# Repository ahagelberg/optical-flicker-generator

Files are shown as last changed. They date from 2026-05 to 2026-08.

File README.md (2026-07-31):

# Optical Flicker Generator

Optical Flicker Generator is a complete hardware + firmware device for controlled high-power optical stimulation.

Current hardware platform:

- Arduino MKR Zero
- Arduino Ethernet Shield
- Custom PCB with high-current LED driver stages

Current software provides:

- Web control page (`/`)
- Web configuration page (`/config`)
- HTTP JSON API
- ASCII shell over Serial and optional Telnet

## Project Scope

- Firmware source code is under `firmware/`.
- Hardware design files (schematics/PCB/manufacturing outputs) are under `hardware/`.

## Documentation

- User manual: `firmware/USER_MANUAL.md`
- Interface/protocol reference: `firmware/PROTOCOL.md`

## Getting Started

1. Flash the firmware to the device.
2. Connect power and Ethernet.
3. Open the control page in a browser using:
   - `http://flicker-<suffix>.local/`, or
   - the IP shown on the device display.

## Repository Layout

- `firmware/` - PlatformIO firmware source and documentation
- `hardware/` - Hardware design files

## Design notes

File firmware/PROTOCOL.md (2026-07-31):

# Optical Flicker Generator — Interface & Protocol Reference

**Document firmware version: 1.1**

Commands and fields are tagged with **Since** (first firmware version that includes them). Untagged items apply since **1.0**. Use `identify` or `status` to read the device firmware version at runtime.

## Overview

The device exposes three interfaces:

| Interface | Transport | Port | Format |
| --- | --- | --- | --- |
| ASCII shell | USB Serial (CDC)  | — | Line-oriented text |
| ASCII shell | Ethernet / Telnet | TCP 23 | Same as Serial |
| HTTP API | Ethernet | TCP 80 | JSON |

All LED control goes through `FlickerController`, so frequency calibration applies uniformly regardless of which interface is used. The output is two hardware channels (MKR Zero D2 and D3) driven in lockstep with the same PWM parameters; there is no per-channel control.

---

## ASCII Shell (Serial + Telnet)

### Framing

- One command per line, terminated by `\n` or `\r\n`.
- Command verb is **case-insensitive**; arguments are case-sensitive where noted.
- Response is a single line terminated by `\r\n` (Arduino `println`).
- Max command line length: 128 bytes (excess bytes are discarded; the line is dropped).
- Partial lines with no new data for 5 s are silently discarded.

### Response format

```
OK                     # success, no payload
OK <payload>           # success with data
ERROR <reason>         # failure; reason is human-readable
```

Errors always begin with the literal string `ERROR`  followed by a short description. Scripts should match on the prefix.

Status/debug lines emitted asynchronously on USB Serial always begin with `# ` and must be ignored by API clients. (**Since 1.1**)

### Command summary

| Command | Since | Description |
| --- | ----- | --- |
| `identify` | 1.0 | Device type, firmware version, hardware ID |
| `status` | 1.1 | One-line `key=value` system status dump |
| `reboot` | 1.1 | Soft-reset the MCU |
| `mode` | 1.0 | Query/set operating mode |
| `frequency` / `freq` | 1.0 | Query/set envelope frequency (Hz) |
| `dutycycle` / `duty` | 1.0 | Query/set duty cycle (%) |
| `intensity` / `int` | 1.0 | Query/set intensity (%) |
| `carrier` | 1.0 | Query/set PWM carrier (Hz), persisted |
| `screensaver` | 1.0 | Query/set display screensaver timeout (s), persisted |
| `calibration` | 1.0 | Print stored frequency calibration table |
| `calibrate` | 1.0 | Start interactive calibration wizard |

---

### Commands

#### `identify`

**Since:** 1.0

Query device identity.

```
→ identify
← OK FLICKER_DEVICE 1.1 A0B1C2D3E4F56789A0B1C2D3E4F56789
```

Payload: `<device_type> <firmware_version> <id>`  
`<id>` is the SAMD21 128-bit hardware serial number encoded as 32 uppercase hex chars.

---

#### `status`

**Since:** 1.1

Dump system status as one line of space-separated `key=value` fields. Values contain no spaces. Parse by splitting on spaces, then on the first `=` in each token.

```
→ status
← OK STATUS device=FLICKER_DEVICE firmware=1.1 id=A0B1C2D3E4F56789A0B1C2D3E4F56789 mode=flicker frequency=50 dutycycle=50 intensity=100 carrier=20000 screensaver=10 dhcp=1 ip=192.168.1.10 ethernet=up hardware=W5500 link=on mdns=flicker-a1b2c3 cal_points=8 wizard=0 uptime_ms=12345
```

| Key | Meaning |
| --- | --- |
| `device` | Device type string |
| `firmware` | Firmware version |
| `id` | 32-char uppercase hex SAMD21 unique ID |
| `mode` | `off` / `constant` / `flicker` / `sinus` |
| `frequency` | Desired envelope Hz |
| `dutycycle` | Duty cycle % |
| `intensity` | Intensity % |
| `carrier` | PWM carrier Hz |
| `screensaver` | Display screensaver timeout (s) |
| `dhcp` | `1` if DHCP enabled, else `0` |
| `ip` | Current IPv4 address (`0.0.0.0` if none) |
| `ethernet` | `up` if hardware + link + IP, else `down` |
| `hardware` | `none` / `W5100` / `W5200` / `W5500` |
| `link` | PHY link `on` / `off` / `unknown` |
| `mdns` | mDNS hostname without `.local` |
| `cal_points` | Stored calibration point count |
| `wizard` | `1` if calibration wizard active |
| `uptime_ms` | Milliseconds since boot |

`status` and `reboot` are accepted even while the calibration wizard is active.

---

#### `reboot`

**Since:** 1.1

Reboot the MCU after queuing the reply.

```
→ reboot
← OK
```

The reply is written to the serial/TCP output path before reset. The USB or TCP connection will drop.

---

#### `mode [value]`

**Since:** 1.0

Query or set the operating mode.

```
→ mode
← OK flicker

→ mode flicker
← OK
```

Valid modes: `off`, `constant`, `flicker`, `sinus`  
Changing mode keeps existing frequency/duty/intensity values; only the mode changes.

| Mode | Description |
| --- | --- |
| `off` | LED output disabled |
| `constant` | Continuous illumination at the configured intensity |
| `flicker`  | Square-wave envelope at configured frequency and duty cycle |
| `sinus` | Sinusoidal envelope at configured frequency |

---

#### `frequency` / `freq [value]`

**Since:** 1.0

Query or set the flicker/sinus frequency in Hz.

```
→ frequency
← OK 50

→ freq 10
← OK

→ freq 0
← ERROR out of range (1-500 Hz)
```

Range: 1–500 Hz  
The value is the **desired** physical Hz; `FlickerController` applies the calibration table before commanding the hardware. Setting frequency does not change mode.

---

#### `dutycycle` / `duty [value]`

**Since:** 1.0

Query or set the duty cycle percentage (flicker mode only; stored for other modes too).

```
→ duty
← OK 50

→ duty 30
← OK

→ duty 5
← ERROR out of range (10-90 %)
```

Range: 10–90 %

---

#### `intensity` / `int [value]`

**Since:** 1.0

Query or set the LED intensity percentage.

```
→ intensity
← OK 100

→ int 75
← OK
```

Range: 0–100 %

---

#### `carrier [value]`

**Since:** 1.0

Query or set the PWM carrier frequency in Hz. The carrier drives intensity modulation in `constant` and `sinus` modes; it has no effect in `flicker` mode. The value is persisted to EEPROM immediately.

```
→ carrier
← OK 20000

→ carrier 10000
← OK

→ carrier 500
← ERROR out of range (1000-50000 Hz)
```

Range: 1 000–50 000 Hz

---

#### `screensaver [value]`

**Since:** 1.0

Query or set the OLED screensaver timeout in seconds. The value is persisted to EEPROM immediately. After this many seconds with no set-button activity, the display enters power-save; a short press wakes it.

```
→ screensaver
← OK 10

→ screensaver 30
← OK

→ screensaver 0
← ERROR out of range (1-600 s)
```

Range: 1–600 s

---

#### `calibration`

**Since:** 1.0

Print the stored frequency calibration table.

```
→ calibration
← OK CAL 0
```

*(no calibration stored)*

```
→ calibration
← OK CAL 8 1:1;5:5;10:10;25:26;50:51;100:103;200:206;500:515
```

*(8 points stored)*

Payload format: `OK CAL <count> [cmd1:meas1;cmd2:meas2;…]`  

- `count` — number of stored calibration points.  
- Each pair is `<commanded_hz>:<measured_hz>` separated by `;`.

---

#### `calibrate`

**Since:** 1.0

Start the interactive frequency calibration wizard.

The wizard drives the LED at each of 8 nominal frequencies (1, 5, 10, 25, 50, 100, 200, 500 Hz) in sequence. At each step, the device replies with a prompt; the user measures the actual output frequency and sends it as a plain integer.

**Wizard session:**

```
→ calibrate
← OK WIZARD 1/8 1        # step/total, target Hz

→ 1                       # measured Hz (integer)
← OK WIZARD 2/8 5

→ 5
← OK WIZARD 3/8 10

→ 11
← OK WIZARD 4/8 25
…
→ 519
← OK WIZARD DONE          # table saved, prior mode restored
```

**Wizard prompt format:** `OK WIZARD <step>/<total> <target_hz>`

While the wizard is active, the shell is in measurement mode — lines that are not a valid unsigned integer receive `ERROR expected measured Hz as integer` and the step is re-prompted. Other commands are rejected except **`status`** and **`reboot`** (**Since 1.1**), which remain available during the wizard.

The wizard forces `flicker` mode during measurement (for a stable square-wave envelope) while preserving the user's configured duty cycle and intensity. Calibration bypass is enabled so raw Hz values drive the hardware. On completion, the prior mode and frequency are restored and calibration is applied immediately.

**Errors:**

```
→ calibrate
← ERROR wizard already active   # sent while wizard is in progress
```

---

### Error reference

| Message | Cause | Since |
| --- | --- | ----- |
| `ERROR empty command` | Line contained no token | 1.0 |
| `ERROR unknown command` | Verb not recognised | 1.0 |
| `ERROR invalid argument` | Argument not parseable | 1.0 |
| `ERROR unknown mode (off constant flicker sinus)` | Unrecognised mode name | 1.0 |
| `ERROR out of range (1-500 Hz)` | Frequency outside 1–500 Hz | 1.0 |
| `ERROR out of range (10-90 %)` | Duty cycle outside 10–90 % | 1.0 |
| `ERROR out of range (0-100 %)` | Intensity outside 0–100 % | 1.0 |
| `ERROR out of range (1000-50000 Hz)` | Carrier frequency outside 1 000–50 000 Hz | 1.0 |
| `ERROR out of range (1-600 s)` | Screensaver timeout outside 1–600 s | 1.0 |
| `ERROR wizard already active` | `calibrate` sent while wizard running | 1.0 |
| `ERROR expected measured Hz as integer` | Non-integer sent during wizard | 1.0 |

---

## HTTP / JSON API

Base URL: `http://<device-ip>/`

Responses use `Content-Type: application/json` and `Connection: close`.

### `GET /api/identify`

```json
{
  "device": "FLICKER_DEVICE",
  "firmware": "1.1",
  "id": "A0B1C2D3E4F56789A0B1C2D3E4F56789"
}
```

---

### `GET /api/state`

Returns the current mode and all parameters.

```json
{
  "mode": "flicker",
  "frequency": 50,
  "dutycycle": 50,
  "intensity": 100
}
```

`frequency` reflects the user's **desired** Hz value, not the calibrated command value sent to hardware.

---

### `POST /api/off`

Turns the LED off. No request body required.

```json
{ "ok": true }
```

---

### `POST /api/constant`

Sets constant mode. Optional JSON body applies parameters before switching.

```json
{ "intensity": 75 }
→
{ "ok": true }
```

---

### `POST /api/flicker`

Sets flicker mode. Optional JSON body applies parameters before switching.

```json
{ "frequency": 10, "dutycycle": 30, "intensity": 80 }
→
{ "ok": true }
```

JSON keys: `frequency` (Hz, 1–500), `dutycycle` (%, 10–90), `intensity` (%, 0–100). All are optional; omit any key to keep the current value.

---

### `POST /api/sinus`

Sets sinus mode. Optional JSON body.

```json
{ "frequency": 25, "intensity": 100 }
→
{ "ok": true }
```

---

### `GET /api/frequency`

```json
{ "frequency": 50 }
```

### `POST /api/frequency`

```json
{ "value": 25 }
→
{ "ok": true }
```

### `GET /api/dutycycle` / `POST /api/dutycycle`

Same pattern. POST body: `{ "value": 40 }`.

### `GET /api/intensity` / `POST /api/intensity`

Same pattern. POST body: `{ "value": 80 }`.

---

### HTTP error responses

```json
{ "error": "Not found" }      // 404 — unknown path
{ "error": "Bad request" }    // 400 — unknown API endpoint
```

Note: the mode-set POST endpoints (`/api/flicker`, `/api/sinus`, etc.) do **not** validate individual parameter ranges — out-of-range values are silently clamped by `FlickerController`. Use the ASCII shell if you need explicit range errors.

---

### Web UI

`GET /` — HTML control page for interactive use.  
`GET /config` — HTML network configuration page (DHCP, static IP/gateway/subnet, PWM carrier frequency).  
`POST /config` — Submit configuration form. Changes take effect on next boot for network settings.

---

## Frequency Calibration

### Concept

Hardware timer resolution means the actual output frequency deviates slightly from the commanded value, especially at the low and high ends of the range. The calibration table stores (commanded Hz, measured Hz) pairs from a one-time wizard run. When a desired frequency `D` is requested, `FlickerController` computes the command value `C` such that the hardware actually outputs `D` Hz, using piecewise-linear inverse interpolation over the stored pairs.

### Math

Points are stored sorted by commanded Hz (the wizard steps are monotonically increasing). For a desired frequency `D`:

1. If the table has fewer than 2 points → identity (`C = D`).
2. If `D ≤ meas[0]` → clamp to `cmd[0]`.
3. If `D ≥ meas[n-1]` → clamp to `cmd[n-1]`.
4. Otherwise find `i` where `meas[i] ≤ D ≤ meas[i+1]` and interpolate:

```
C = cmd[i] + (D - meas[i]) × (cmd[i+1] - cmd[i]) / (meas[i+1] - meas[i])
```

Integer arithmetic; uses 64-bit intermediate to avoid overflow.

### Persistence

The calibration table is stored in EEPROM (SAMD21 flash emulation via `FlashStorage_SAMD`) as part of `StoredConfig` (magic `0x464C4353`). It is treated as factory data and is **not** cleared by a factory reset. Re-running `calibrate` replaces the entire table.

---

## Network configuration

Configured via the `/config` web page or directly in EEPROM. Stored fields:

| Field | Default |
| --- | --- |
| DHCP | enabled |
| Static IP | 0.0.0.0 |
| Gateway | 0.0.0.0 |
| Subnet | 0.0.0.0 |
| PWM carrier Hz | 20000 |

The PWM carrier frequency (1 000–50 000 Hz) controls the intensity modulation rate in `constant` and `sinus` modes. It has no effect in `flicker` mode.

Network changes take effect after a power cycle.

---

## mDNS discovery

The device advertises itself on the LAN via **mDNS/DNS-SD** (UDP port 5353).

| Item | Value |
| ---- | ----- |
| Hostname | `flicker-` + last 6 hex digits of device serial (e.g. `flicker-a1b2c3.local`) |
| Service | `_http._tcp` on port 80 |

After the device has an IP address, open `http://flicker-<suffix>.local/` in a browser, or ping the hostname:

```
ping flicker-a1b2c3.local
```

**Linux:** `avahi-browse -a | grep -i flicker`

**macOS:** mDNS is built in; Safari Bonjour bookmarks also list `_http._tcp` services.

**Windows:** Built-in mDNS support varies by version. Install [Bonjour Print Services](https://support.apple.com/kb/DL999) if `.local` names do not resolve.

mDNS is always enabled when Ethernet has a valid IP. No configuration required.

---

## Set button

Short press on set button wakes the display from screensaver.

Hold set button for **10 s** to perform a factory reset: network settings and PWM carrier Hz are cleared to defaults. The frequency calibration table is **preserved**.

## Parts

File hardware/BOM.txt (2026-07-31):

Model				Manufacturer	Description								Count	á-price (SEK)	price (SEK)
ABX00012			Arduino			Arduino MKR ZERO Microcontroller		1		313.00			313.00
ASX00006			Arduino			Arduino MKR ETH-shield					1		328.00			328.00
TSR 1-2450			Traco			TracoPower voltage reg 5V 1A			1		67.00			67.00
IRLML6344TRPBF		Infineon		MOSFET N-ch 5A 30V SOT-23				4		5.92			23.68
B340AE-13			DiodesZetex		Schottky-diode 40V 3A SMA				4		1.81			7.24
									Resistor 220R 0805						4		0.10			0.40
									Resistor 10K 0805						4		0.10			0.40
EEEFK1H221GP		Panasonic		Electrolytic 220uF 50V SMD				1		12.00			12.00
MDOB128064V2V-WI	Midas			OLED display 0.96" 128x64px				1		156.00			156.00	
1213C BLACK			APEM			Tryckknapp panel 12.2mm					1		67.00			67.00
XHP-2				JST				XHP connector, female, 2-way, 2.5mm		6		0.74			4.44
XHP-4				JST				XHP connector, female, 4-way, 2.5mm		1		1.20			1.20
B2B-XH-A(LF)(SN)	JST				XHP PCB connector, male, 2-way, 2.5mm	4		1.76			7.04
B4B-XH-A(LF)(SN)	JSP				XHP PCB connector, male, 4-way, 2.5mm	1		1.44			1.44
SXH-001T-P0.6N		JST				XH contact element, crimp, AWG22-26		14		0.828			11.592
GST120A24-P1M		Meanwell		AC/DC-adapter 120W 24VDC 5A				1		450.25			450.25
RSTA4265			Radium			LED-list 5000mm 4000K 24V 1000lm/m		1		505.80			505.80
124-618				RS PRO			M12 connector straight male 4-way		2		57.68			115.36
M12A-04PFFS-SH8001	Amphenol		M12 connector panel female 4-way		2		65.30			130.60

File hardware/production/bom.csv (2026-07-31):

Designator | Footprint | Quantity | Value | LCSC Part #
C1 | CP_Elec_10x10.5 | 1 | 470μF
D1, D2, D3, D4 | D_SMA | 4 | D_Schottky
J1, J2, J3, J4 | JST_XH_B2B-XH-A_1x02_P2.50mm_Vertical | 4 | Channel 1
J5 | JST_XH_B2B-XH-A_1x02_P2.50mm_Vertical | 1 | Reset Button
J6 | JST_XH_B2B-XH-A_1x02_P2.50mm_Vertical | 1 | Set Button
J7 | JST_XH_B4B-XH-A_1x04_P2.50mm_Vertical | 1 | OLED 128X64 0.96
J8 | JST_XH_B2B-XH-A_1x02_P2.50mm_Vertical | 1 | 24V
Q1, Q2, Q3, Q4 | SOT-23 | 4 | AO3400A / IRLML6344TRPBF
R1, R3, R5, R7 | 0805 | 4 | 220Ω
R2, R4, R6, R8 | 0805 | 4 | 10K
U1 | Arduino_MKR | 1 | Arduino_MKR
U2 | Converter_DCDC_TRACO_TSR0.5-24xx_TSR0.5-24xxx_THT | 1 | TSR0.5-2450

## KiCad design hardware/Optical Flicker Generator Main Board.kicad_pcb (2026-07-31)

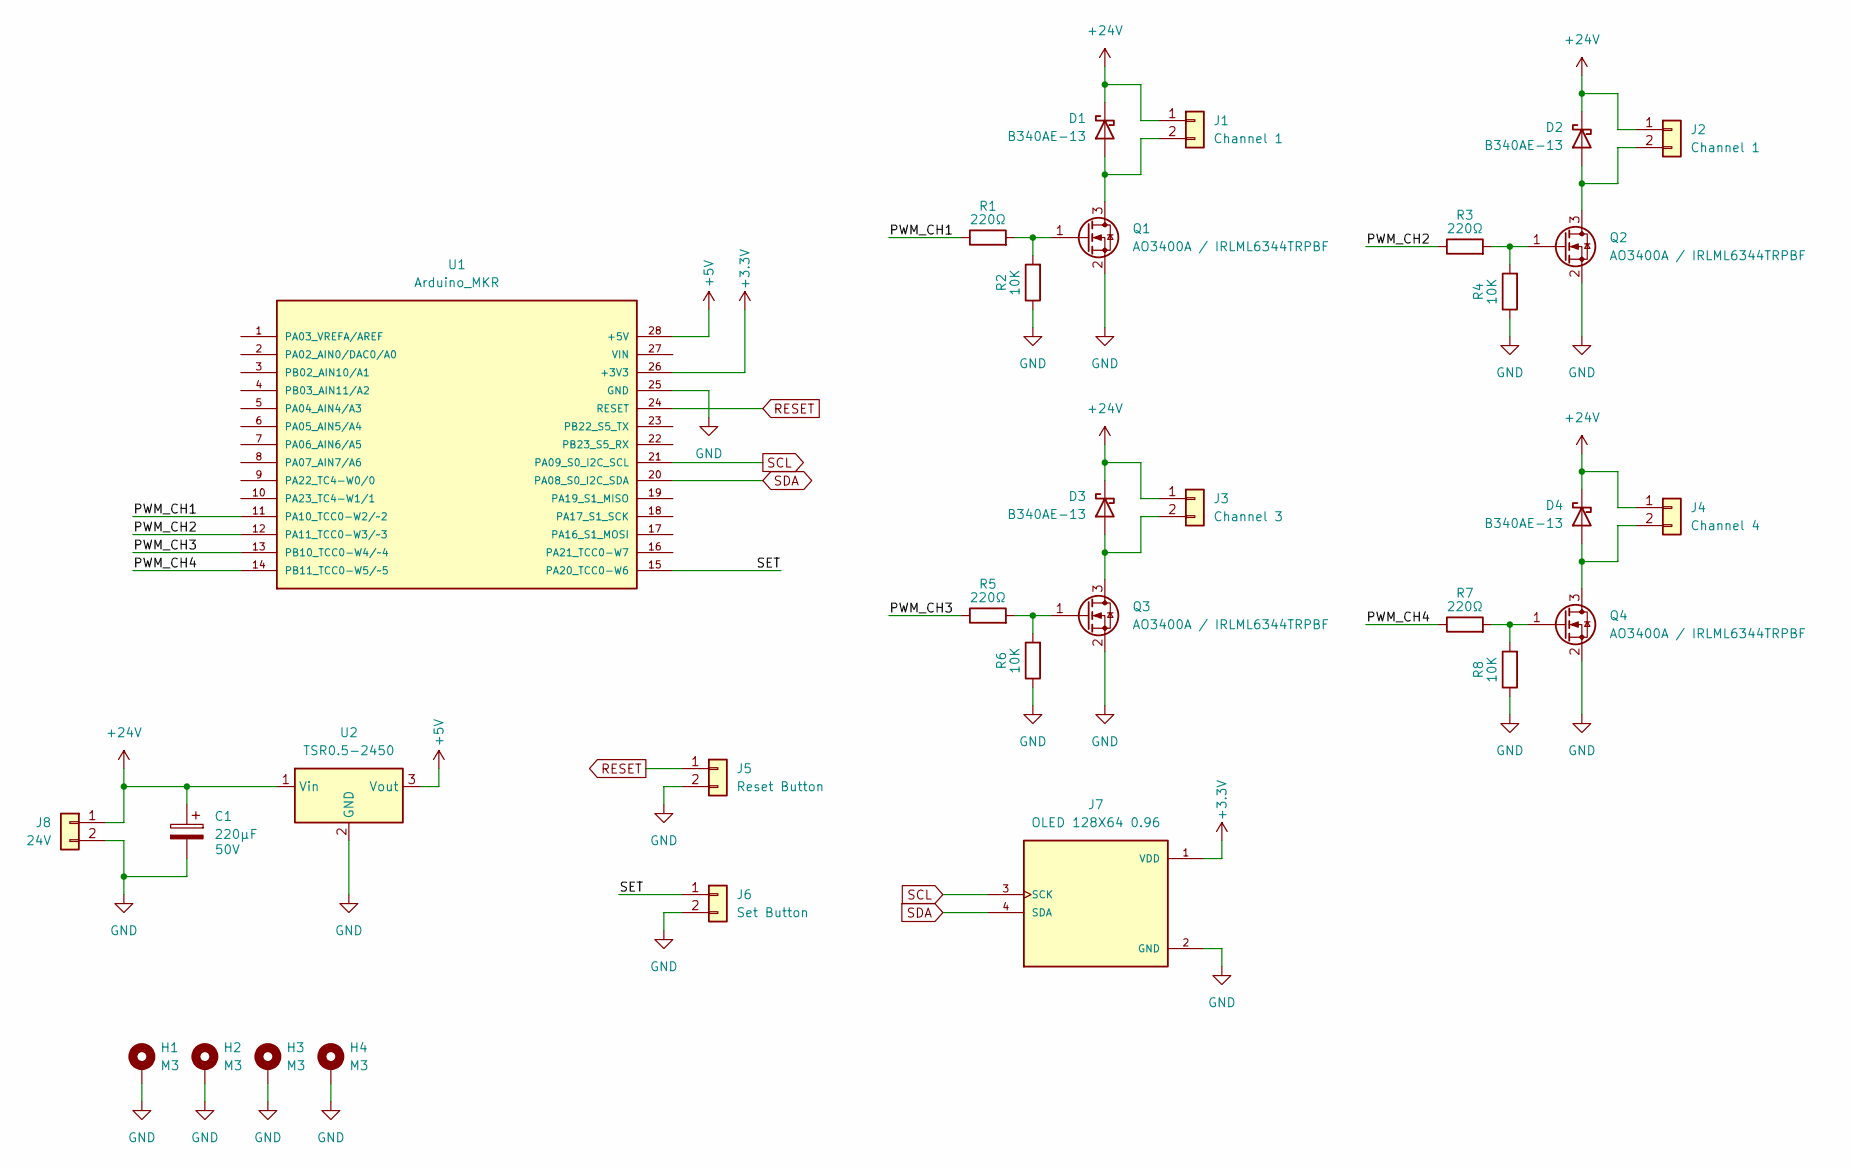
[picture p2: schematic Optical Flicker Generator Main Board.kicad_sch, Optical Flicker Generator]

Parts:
C1: 220μF; CP_Elec_10x10.5; Voltage 50V
D1, D2, D3, D4: B340AE-13; D_SMA
H1, H2, H3, H4: M3; MountingHole_3.2mm_M3_Pad
J1, J2: Channel 1; JST_XH_B2B-XH-A_1x02_P2.50mm_Vertical
J3: Channel 3; JST_XH_B2B-XH-A_1x02_P2.50mm_Vertical
J4: Channel 4; JST_XH_B2B-XH-A_1x02_P2.50mm_Vertical
J5: Reset Button; JST_XH_B2B-XH-A_1x02_P2.50mm_Vertical
J6: Set Button; JST_XH_B2B-XH-A_1x02_P2.50mm_Vertical
J7: OLED 128X64 0.96; JST_XH_B4B-XH-A_1x04_P2.50mm_Vertical; PARTREV NA
J8: 24V; JST_XH_B2B-XH-A_1x02_P2.50mm_Vertical
Q1, Q2, Q3, Q4: AO3400A / IRLML6344TRPBF; SOT-23
R1, R3, R5, R7: 220Ω; R_0805_2012Metric
R2, R4, R6, R8: 10K; R_0805_2012Metric
U1: Arduino_MKR; PARTREV 5
U2: TSR0.5-2450; Converter_DCDC_TRACO_TSR0.5-24xx_TSR0.5-24xxx_THT

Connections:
+3.3V: J7.1 (VDD), U1.26 (+3V3)
+5V: U1.28 (+5V), U2.3 (Vout)
+24V: C1.1, D1.1 (K), D2.1 (K), D3.1 (K), D4.1 (K), J1.1, J2.1, J3.1, J4.1, J8.1, U2.1 (Vin)
/PWM_CH1: R1.1, U1.11 (PA10_TCC0-W2/~2)
/PWM_CH2: R3.1, U1.12 (PA11_TCC0-W3/~3)
/PWM_CH3: R5.1, U1.13 (PB10_TCC0-W4/~4)
/PWM_CH4: R7.1, U1.14 (PB11_TCC0-W5/~5)
/SET: J6.1, U1.15 (PA20_TCC0-W6)
GND: C1.2, H1.1 (1_1), H2.1 (1_1), H3.1 (1_1), H4.1 (1_1), J5.2, J6.2, J7.2 (GND), J8.2, Q1.2 (S), Q2.2 (S), Q3.2 (S), Q4.2 (S), R2.1, R4.1, R6.1, R8.1, U1.25 (GND), U2.2 (GND)
unnamed: D1.2 (A), J1.2, Q1.3 (D)
unnamed: D2.2 (A), J2.2, Q2.3 (D)
unnamed: D3.2 (A), J3.2, Q3.3 (D)
unnamed: D4.2 (A), J4.2, Q4.3 (D)
unnamed: Q1.1 (G), R1.2, R2.2
unnamed: Q2.1 (G), R3.2, R4.2
unnamed: Q3.1 (G), R5.2, R6.2
unnamed: Q4.1 (G), R7.2, R8.2
RESET: J5.1, U1.24 (RESET)
SCL: J7.3 (SCK), U1.21 (PA09_S0_I2C_SCL)
SDA: J7.4 (SDA), U1.20 (PA08_S0_I2C_SDA)

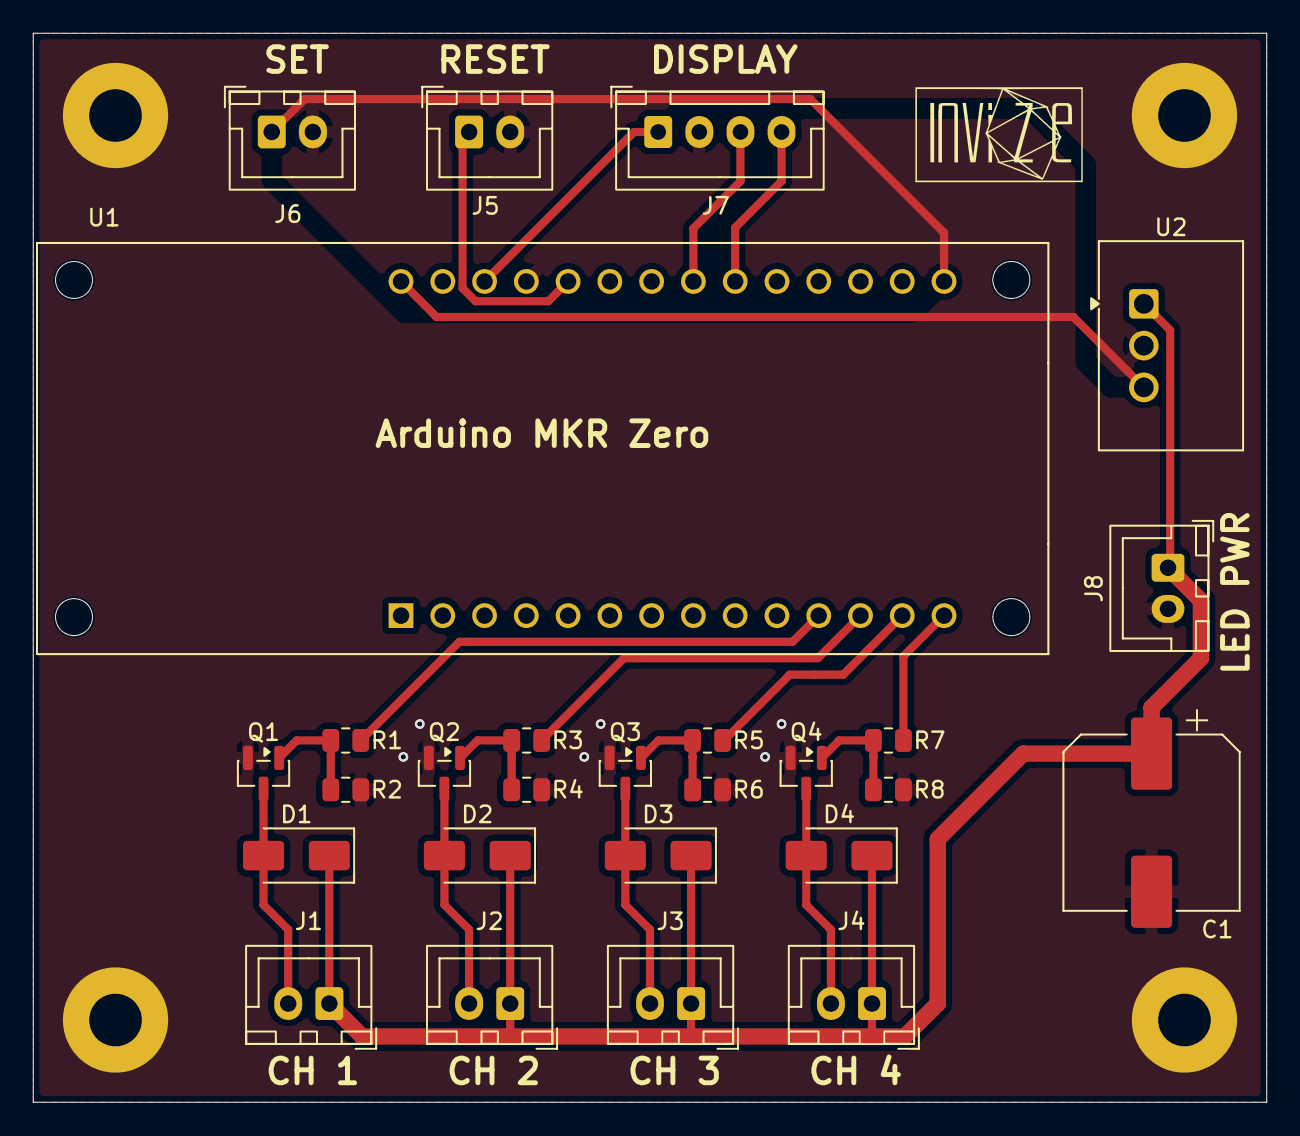
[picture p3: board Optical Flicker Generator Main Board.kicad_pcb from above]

Board: 2 copper layers, 75.0 x 65.0 mm, 33 parts (1 on the bottom side), 20 nets.

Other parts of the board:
Ref**: Val**; Invize logo 10x6 - no tagline - Back
Ref**#2: Val**; Invize logo 10x6 - no tagline - Back

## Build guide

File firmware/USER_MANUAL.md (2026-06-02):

# Optical Flicker Generator - User Manual

## Purpose

This device generates controlled LED light output for optical flicker experiments.  
You can operate it from a browser on your local network, or via one of several APIs.

---

## Quick Start

1. Connect the hardware:
   - Connect Ethernet to your LAN.
   - Power the device.
2. Wait for startup to complete (display shows mode and settings).
3. Open the control page:
   - Use the IP shown on the device display, or
   - Try `http://flicker-xxxxxx.local/` (where `xxxxxx` is the device suffix)
4. Use the **Control Page** to set mode and output parameters.
5. If needed, open **Configuration** from the control page to change network settings.

---

## Accessing the Web Interface

- Main control page: `GET /`  
- Configuration page: `GET /config`

If `*.local` names do not resolve on your computer, use the device IP address shown on the display.

---

## Using the Control Page

The control page is for direct use and testing.

### Mode Selection

You can select one of four modes:

- **Off**: output disabled
- **Constant**: continuous light at selected intensity
- **Flicker**: square-wave modulation using frequency + duty cycle + intensity
- **Sinus**: sinusoidal modulation using frequency + intensity

### Parameters

- **Frequency (Hz):** 1-500
- **Duty cycle (%):** 10-90
- **Intensity (%):** 0-100

Click **Apply** to send the selected mode and parameter values to the device.

### Typical Workflow

1. Choose mode (`flicker`, `sinus`, `constant`, or `off`)
2. Set frequency and intensity (and duty for flicker)
3. Click **Apply**
4. Verify output on the device and experiment setup

---

## Using the Configuration Page

Open `/config` from the control page when you need to change network or hardware-related settings.

### Network Settings

- **Use DHCP** (checkbox)
  - Enabled: router assigns IP automatically
  - Disabled: device uses static values entered below
- **Static IP settings** (used when DHCP is disabled):
  - IP address
  - Gateway
  - Subnet mask

### Connectivity Settings

- **Enable Telnet access (port 23)**  
  Disabled by default. Enable only on trusted networks.

### Hardware/Display Settings

- **PWM carrier frequency (Hz):** 1,000-50,000
- **Display screensaver timeout (s):** 1-600

Click **Save** to store changes.

### When Changes Take Effect

- Network-related changes are applied after a power cycle.
- Other saved settings are applied immediately.

---

## Factory Reset (Set Button)

- **Short press:** wakes display from screensaver.
- **Press and hold for 10 seconds:** restores network and configuration defaults.

---

## Troubleshooting

### Cannot open the control page

- Check Ethernet cable and LAN connection.
- Confirm the device has an IP address on the display.
- Try opening the page by IP instead of `*.local` hostname.

### Wrong or no light output

- Confirm mode is not `off`.
- Verify parameter ranges on the control page.
- Click **Apply** after any change.

### Lost access after network changes

- Power-cycle the device.
- If static IP is misconfigured, perform factory reset and reconnect using DHCP defaults.

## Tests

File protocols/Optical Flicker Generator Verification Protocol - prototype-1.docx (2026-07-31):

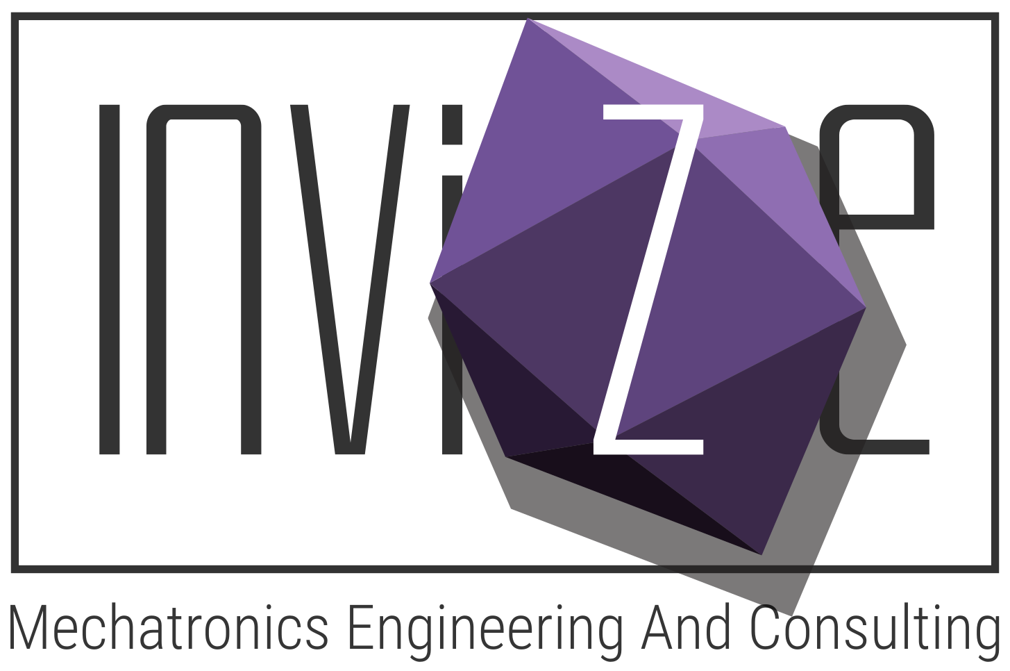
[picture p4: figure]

INVIZE AB

EQUIPMENT VERIFICATION PROTOCOL

Device Under Test: | Optical Flicker Generator | Date of Test: | 2026-05-18
Model / Revision: | Rev 1 | Location: | ESS, Lund, Sweden
Serial Number: | prototype-1 | Operator: | Andreas Hagelberg
Ambient Temp: | 20 °C | Relative Humidity: | 30% RH

1. Reference System Conditions

Measurements were captured using an Aim-TTi TF930 Universal Frequency Counter with an internal 10 MHz TCXO base clock source. Standard baseline specification limits determine the combined reference standard uncertainty profile to be ±1.2 ppm. Raw readout digits were manually truncated from the faceplate to address fluctuating sub-millihertz jitter.

2. Verification Data Table

Nominal / Set Frequency (Hz) | Measured Frequency (Hz) | Absolute Error (Hz) | Relative Error (ppm) | TF930 Timebase Uncertainty (Hz)
1 | 1.0001 | +0.0001 | +100.00 ppm | ±0.0000012
10 | 10.001 | +0.0010 | +100.00 ppm | ±0.0000120
50 | 50.006 | +0.0060 | +120.00 ppm | ±0.0000600
100 | 100.01 | +0.0100 | +100.00 ppm | ±0.0001200
200 | 200.02 | +0.0200 | +100.00 ppm | ±0.0002400
500 | 500.06 | +0.0600 | +120.00 ppm | ±0.0006000

3. Characterization Summary

The Optical Flicker Generator demonstrates a predictable, highly linear systematic offset grouped consistently between +100.00 ppm and +120.00 ppm across its test envelope. The uniform distribution suggests a stable clock scaling profile in the base timer/oscillator subsystem rather than dynamic firmware lag. Reference instrument uncertainty remains two orders of magnitude below observed deviations, confirming statistical validity of the performance window.

4. Approvals and Sign-off

______________________________
Andreas Hagelberg
Invize AB
Date: 2026-05-18

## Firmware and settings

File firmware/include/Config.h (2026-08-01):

#ifndef CONFIG_H
#define CONFIG_H

#define FIRMWARE_VERSION      "1.2"

/* MKR Zero + MKR ETH shield */
#define PIN_LED_OUTPUT_A      2   /* TCC1 WO[0] */
#define PIN_LED_OUTPUT_B      3   /* TCC1 WO[1] — same waveform as A */
#define PIN_RESET_BUTTON      6   /* OLED wake + factory reset (long hold) */
#define PIN_ETHERNET_CS       5

/* Envelope / modulation frequency (Hz), flicker and sinus */
#define MIN_FREQ_HZ          1
#define MAX_FREQ_HZ          500
#define DEFAULT_FREQ_HZ      50
#define MIN_DUTY_PERCENT     10
#define MAX_DUTY_PERCENT     90
#define DEFAULT_DUTY_PERCENT 50
#define MIN_INTENSITY_PERCENT 0
#define MAX_INTENSITY_PERCENT 100
#define DEFAULT_INTENSITY_PERCENT 100

/* Fast PWM carrier for intensity shaping (constant + sinus); ignored in pure flicker envelope path */
#define MIN_CARRIER_HZ        1000
#define MAX_CARRIER_HZ        50000
#define DEFAULT_CARRIER_HZ    20000

#define BUTTON_HOLD_MS        10000
#define DISPLAY_UPDATE_MS     500
#define MIN_DISPLAY_SCREENSAVER_S  1
#define MAX_DISPLAY_SCREENSAVER_S  600
#define DEFAULT_DISPLAY_SCREENSAVER_S 10
#define SERIAL_LINE_TIMEOUT_MS 5000
#define PROTOCOL_CMD_LINE_BUFFER_MAX 128
#define PROTOCOL_PARSE_CMD_MAX       32
#define PROTOCOL_PARSE_ARGS_MAX      64

#define SOCKET_PORT           23
#define HTTP_PORT             80

#define MDNS_PORT                 5353
#define MDNS_HOSTNAME_PREFIX      "flicker-"
#define MDNS_HOSTNAME_PREFIX_LEN  8
#define MDNS_HOSTNAME_SUFFIX_LEN  6
#define MDNS_HOSTNAME_BUFFER_LEN  (MDNS_HOSTNAME_PREFIX_LEN + MDNS_HOSTNAME_SUFFIX_LEN + 1)
#define MDNS_HTTP_SERVICE_NAME    "Flicker._http"

#define IPV4_STRING_BUFFER_LEN 16

#define CAL_MAX_POINTS 8

/* Sized for single-line `status` key=value reply. */
#define PROTOCOL_RESPONSE_MAX 384

#endif

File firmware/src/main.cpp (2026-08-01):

#include <Arduino.h>
#include "Config.h"
#include "ConfigStore.h"
#include "FrequencyCalibration.h"
#include "LedDriver.h"
#include "FlickerController.h"
#include "CommandShell.h"
#include "SerialCommand.h"
#include "Display.h"
#include "SocketServer.h"
#include "WebServer.h"
#include "ResetButton.h"
#include "MdnsAdvertiser.h"
#include "DebugLog.h"
#include "DeviceInfo.h"
#include "NetworkFormat.h"
#include "EthernetStatus.h"
#include "SerialTx.h"
#include <Ethernet.h>

ConfigStore configStore;
FrequencyCalibration freqCal;
LedDriver ledDriver;
FlickerController flickerController(ledDriver, freqCal);
CommandShell commandShell(flickerController, freqCal, configStore);
SerialCommand serialCommand(commandShell);
Display display(flickerController, configStore);
SocketServer socketServer(commandShell);
WebServer webServer(flickerController, configStore);
ResetButton resetButton(configStore);
MdnsAdvertiser mdnsAdvertiser;

void setup() {
    /* OLED first — never block on USB CDC before user-visible boot feedback. */
    display.showBootSplash();
    resetButton.begin();
    Serial.begin(115200);
    debugLog("booting...");
    configStore.load();
    ConfigStore::CalibrationData calData = configStore.getCalibrationData();
    freqCal.load(calData);
    flickerController.setCarrierHz(configStore.getCarrierHz());
    Ethernet.init(PIN_ETHERNET_CS);
    uint8_t mac[DEVICE_INFO_MAC_LEN];
    DeviceInfo::writeMacAddress(mac, sizeof(mac));
    if (configStore.getUseDhcp()) {
        Ethernet.begin(mac);
    } else {
        uint8_t ip[4], gw[4], sn[4];
        configStore.getIp(ip);
        configStore.getGateway(gw);
        configStore.getSubnet(sn);
        /* Fourth arg is DNS server; gateway is used until config stores DNS separately. */
        Ethernet.begin(mac, ip, gw, gw, sn);
    }
    ethernetPoll();
    char idHex[DEVICE_INFO_ID_HEX_BUFFER_LEN];
    DeviceInfo::writeDeviceIdHex(idHex, sizeof(idHex));
    debugLogf("boot %s %s id=%s",
              DeviceInfo::deviceType(), DeviceInfo::firmwareVersion(), idHex);
    {
        char macStr[DEVICE_INFO_MAC_STRING_BUFFER_LEN];
        DeviceInfo::writeMacAddressString(macStr, sizeof(macStr));
        debugLogf("ethernet mac=%s", macStr);
    }
    debugLogf("config dhcp=%u carrier=%lu Hz screensaver=%u s cal_points=%u",
              (unsigned)configStore.getUseDhcp(),
              (unsigned long)configStore.getCarrierHz(),
              (unsigned)configStore.getScreensaverTimeoutS(),
              (unsigned)calData.count);
    {
        char ipStr[IPV4_STRING_BUFFER_LEN];
        formatIpv4(ethernetLocalIp(), ipStr, sizeof(ipStr));
        debugLogf("ethernet ip=%s hardware=%s link=%s",
                  ipStr, ethernetHardwareLabel(), ethernetLinkLabel());
    }
    flickerController.begin();
    display.begin();
    if (ethernetHardwarePresent()) {
        socketServer.begin();
        webServer.begin();
    }
    debugLog("boot complete");
}

void loop() {
    serialCommand.poll();
    serialTxPoll();
    ethernetPoll();
    static bool networkServicesActive = false;
    if (ethernetIsUp()) {
        socketServer.poll();
        webServer.poll();
        mdnsAdvertiser.poll();
        networkServicesActive = true;
    } else if (networkServicesActive) {
        socketServer.stopClient();
        mdnsAdvertiser.stop();
        networkServicesActive = false;
    }
    display.update();
    resetButton.poll();
}

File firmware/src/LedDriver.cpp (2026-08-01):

#include "LedDriver.h"
#include "Config.h"
#include "wiring_private.h"
#include <sam.h>

static inline void syncTCC(Tcc* TCCx) {
    while (TCCx->SYNCBUSY.reg) {}
}

LedDriver* LedDriver::instance_ = nullptr;

static const uint32_t F_CPU_HZ = 48000000u;
/* SAMD21 TC prescaler enum values map to divisors {1,2,4,8,16,64,256,1024}, not 2^n for index ≥ 5 */
static const uint32_t TC4_PRESCALER_DIV[] = {1, 2, 4, 8, 16, 64, 256, 1024};
static const uint8_t TC4_PRESCALER_DIV_COUNT = 8;
static const uint8_t SINE_TABLE_SIZE = 64;
/* 12-bit sine: round(2048 + 2047 * sin(2π i / 64)), i = 0..63 */
static const uint16_t sineTable[SINE_TABLE_SIZE] = {
    2048, 2249, 2447, 2642, 2831, 3013, 3185, 3347, 3495, 3630, 3750, 3853, 3939, 4007, 4056, 4085,
    4095, 4085, 4056, 4007, 3939, 3853, 3750, 3630, 3495, 3347, 3185, 3013, 2831, 2642, 2447, 2249,
    2048, 1847, 1649, 1454, 1265, 1083, 911, 749, 601, 466, 346, 243, 157, 89, 40, 11,
    1, 11, 40, 89, 157, 243, 346, 466, 601, 749, 911, 1083, 1265, 1454, 1649, 1847
};

LedDriver::LedDriver()
    : useCarrier_(false), carrierHz_(DEFAULT_CARRIER_HZ), carrierPer_(0),
      flickerIntensityPercent_(100), sinusMode_(false), sinusIndex_(0) {
    instance_ = this;
}

void LedDriver::begin() {
    setupPins();
    setOff();
}

void LedDriver::setupPins() {
    pinMode(PIN_LED_OUTPUT_A, OUTPUT);
    pinMode(PIN_LED_OUTPUT_B, OUTPUT);
    pinPeripheral(PIN_LED_OUTPUT_A, PIO_TIMER);
    pinPeripheral(PIN_LED_OUTPUT_B, PIO_TIMER);
}

void LedDriver::setTcc1Enabled(bool on) {
    if (on) {
        GCLK->CLKCTRL.reg = (uint16_t)(GCLK_CLKCTRL_CLKEN | GCLK_CLKCTRL_GEN_GCLK0 | GCLK_CLKCTRL_ID(GCM_TCC0_TCC1));
        while (GCLK->STATUS.bit.SYNCBUSY) {}
        TCC1->CTRLA.bit.ENABLE = 1;
        syncTCC(TCC1);
    } else {
        TCC1->CTRLA.bit.ENABLE = 0;
        syncTCC(TCC1);
    }
}

/* Mirror compare to both WO outputs so D2 and D3 stay identical */
void LedDriver::setTcc1CompareBoth(uint32_t cc) {
    TCC1->CC[0].reg = cc;
    TCC1->CC[1].reg = cc;
    syncTCC(TCC1);
}

void LedDriver::setCarrierHz(uint32_t hz) {
    if (hz < MIN_CARRIER_HZ) hz = MIN_CARRIER_HZ;
    if (hz > MAX_CARRIER_HZ) hz = MAX_CARRIER_HZ;
    carrierHz_ = hz;
}

void LedDriver::setupTcc1CarrierPwm() {
    const uint32_t prescaler = 1;
    carrierPer_ = (F_CPU_HZ / 2) / (carrierHz_ * prescaler);
    if (carrierPer_ > 0xFFFFFFu) carrierPer_ = 0xFFFFFFu;
    TCC1->CTRLA.bit.ENABLE = 0;
    syncTCC(TCC1);
    GCLK->CLKCTRL.reg = (uint16_t)(GCLK_CLKCTRL_CLKEN | GCLK_CLKCTRL_GEN_GCLK0 | GCLK_CLKCTRL_ID(GCM_TCC0_TCC1));
    while (GCLK->STATUS.bit.SYNCBUSY) {}
    TCC1->WAVE.reg = TCC_WAVE_WAVEGEN_DSBOTH;
    syncTCC(TCC1);
    TCC1->PER.reg = carrierPer_;
    syncTCC(TCC1);
    setTcc1CompareBoth(0);
    TCC1->CTRLA.reg = TCC_CTRLA_PRESCALER_DIV1 | TCC_CTRLA_ENABLE;
    syncTCC(TCC1);
}

/* MC0 / MC1 interrupts at flicker rate (duty split) or faster tick for sinus stepping */
void LedDriver::configureTc4AtRate(uint32_t matchHz, bool envelopeWithDuty, uint8_t dutyPercent) {
    PM->APBCMASK.reg |= PM_APBCMASK_TC4;
    GCLK->CLKCTRL.reg = (uint16_t)(GCLK_CLKCTRL_CLKEN | GCLK_CLKCTRL_GEN_GCLK0 | GCLK_CLKCTRL_ID(GCM_TC4_TC5));
    while (GCLK->STATUS.bit.SYNCBUSY) {}
    TC4->COUNT16.CTRLA.bit.ENABLE = 0;
    while (TC4->COUNT16.STATUS.bit.SYNCBUSY) {}
    TC4->COUNT16.INTENCLR.reg = TC_INTENCLR_MC0 | TC_INTENCLR_MC1;
    TC4->COUNT16.INTFLAG.reg = TC_INTFLAG_MC0 | TC_INTFLAG_MC1;
    TC4->COUNT16.CTRLA.reg = TC_CTRLA_MODE_COUNT16 | TC_CTRLA_WAVEGEN_MFRQ;
    uint8_t prescIdx = 0;
    uint32_t perVal = F_CPU_HZ / (matchHz * TC4_PRESCALER_DIV[prescIdx]);
    while (perVal > 65535u && prescIdx < TC4_PRESCALER_DIV_COUNT - 1) {
        prescIdx++;
        perVal = F_CPU_HZ / (matchHz * TC4_PRESCALER_DIV[prescIdx]);
    }
    if (perVal > 65535u) perVal = 65535u;
    if (perVal == 0u) perVal = 1u;
    TC4->COUNT16.CTRLA.bit.PRESCALER = prescIdx;
    const uint16_t perReg = (uint16_t)(perVal - 1u);
    TC4->COUNT16.CC[0].reg = perReg;
    if (envelopeWithDuty) {
        TC4->COUNT16.CC[1].reg = (uint16_t)(((uint32_t)perReg * (uint32_t)dutyPercent) / 100u);
        TC4->COUNT16.INTENSET.reg = TC_INTENSET_MC0 | TC_INTENSET_MC1;
    } else {
        TC4->COUNT16.CC[1].reg = 0;
        TC4->COUNT16.INTENSET.reg = TC_INTENSET_MC0;
    }
    while (TC4->COUNT16.STATUS.bit.SYNCBUSY) {}
    NVIC_EnableIRQ(TC4_IRQn);
    NVIC_SetPriority(TC4_IRQn, 1);
    TC4->COUNT16.CTRLA.bit.ENABLE = 1;
    while (TC4->COUNT16.STATUS.bit.SYNCBUSY) {}
}

void LedDriver::setOff() {
    sinusMode_ = false;
    useCarrier_ = false;
    NVIC_DisableIRQ(TC4_IRQn);
    TCC1->CTRLA.bit.ENABLE = 0;
    syncTCC(TCC1);
    digitalWrite(PIN_LED_OUTPUT_A, LOW);
    digitalWrite(PIN_LED_OUTPUT_B, LOW);
}

void LedDriver::setConstant(uint8_t intensityPercent) {
    sinusMode_ = false;
    NVIC_DisableIRQ(TC4_IRQn);
    useCarrier_ = false;
    setupTcc1CarrierPwm();
    /* CC sets off-time for this pinmux polarity */
    uint32_t cc = (carrierPer_ * (100u - (uint32_t)intensityPercent)) / 100u;
    setTcc1CompareBoth(cc);
    setTcc1Enabled(true);
}

void LedDriver::setFlicker(uint32_t freqHz, uint8_t dutyPercent, uint8_t intensityPercent) {
    sinusMode_ = false;
    flickerIntensityPercent_ = intensityPercent;
    useCarrier_ = true;
    NVIC_DisableIRQ(TC4_IRQn);
    setupTcc1CarrierPwm();
    setTcc1CompareBoth(0);
    setTcc1Enabled(true);
    configureTc4AtRate(freqHz, true, dutyPercent);
}

void LedDriver::setSinus(uint32_t freqHz, uint8_t intensityPercent) {
    NVIC_DisableIRQ(TC4_IRQn);
    useCarrier_ = true;
    sinusMode_ = true;
    flickerIntensityPercent_ = intensityPercent;
    setupTcc1CarrierPwm();
    setTcc1CompareBoth(0);
    setTcc1Enabled(true);
    sinusIndex_ = 0;
    const uint32_t isrFreq = freqHz * (uint32_t)SINE_TABLE_SIZE;
    configureTc4AtRate(isrFreq, false, 0);
}

/* ISR: avoid SYNCBUSY wait — write CC registers directly */
void LedDriver::sinusTimerIsr() {
    LedDriver& d = *instance_;
    if (d.carrierPer_ == 0) return;
    uint16_t raw = sineTable[d.sinusIndex_];
    d.sinusIndex_++;
    if (d.sinusIndex_ >= SINE_TABLE_SIZE) d.sinusIndex_ = 0;
    uint32_t onCc = ((uint32_t)raw * (uint32_t)d.flickerIntensityPercent_ * d.carrierPer_) / (100u * 4095u);
    uint32_t cc = (onCc >= d.carrierPer_) ? 0u : (d.carrierPer_ - onCc);
    TCC1->CC[0].reg = cc;
    TCC1->CC[1].reg = cc;
    TC4->COUNT16.INTFLAG.reg = TC_INTFLAG_MC0;
}

void LedDriver::flickerTimerIsr() {
    LedDriver& d = *instance_;
    if (!d.useCarrier_ || d.carrierPer_ == 0) return;
    uint32_t cc;
    if (TC4->COUNT16.INTFLAG.bit.MC0) {
        TC4->COUNT16.INTFLAG.reg = TC_INTFLAG_MC0;
        cc = (d.carrierPer_ * (100u - (uint32_t)d.flickerIntensityPercent_)) / 100u;
    } else {
        TC4->COUNT16.INTFLAG.reg = TC_INTFLAG_MC1;
        cc = d.carrierPer_;
    }
    TCC1->CC[0].reg = cc;
    TCC1->CC[1].reg = cc;
}
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

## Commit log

2026-06-01 Updated name of device in web pages.
2026-07-31 Firmware now tolerate missing hardware. Added debug output on serial. Added reboot and status commands to serial shell.
    [Config.h]
2026-07-31 Added discovery tool for detecting devices on local network.
2026-07-31 Added protocol document for calibration
2026-07-31 Added hardware
    [Optical Flicker Generator Main Board.kicad_pcb, Optical Flicker Generator Main Board.kicad_sch, bom.csv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]
2026-08-01 Fixed corrupt sinus LUT
    [LedDriver.cpp]
2026-08-01 Made sure devices get unique MAC address derived from chip ID
